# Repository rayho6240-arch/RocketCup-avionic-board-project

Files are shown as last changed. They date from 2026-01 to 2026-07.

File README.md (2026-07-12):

# 🚀 RocketCup Avionic Board Project (成大 ISP 航電組)

歡迎來到成大 ISP 航電組的協作平台！這裡存放了我們為比賽設計的所有電路圖、PCB 檔案以及相關硬體參考資料。

為了方便大家協作、快速找到規格書，我們對專案資料夾進行了全面整合與邏輯分類。請大家開發前務必詳細閱讀以下指南。

---

## 📂 檔案結構說明 (去哪裡找你的檔案與資料？)

我們採用結構化、模組化的資料夾配置。請在您負責的子專案資料夾內開發，並參考對應的規格書：

### 1️⃣ 核心開發專案 (由 Git 進行版本控制)
* **[hardware/big_avionic/](hardware/big_avionic/)**: 大火箭航電主板專區 (內附 `備注.md` 進度檔)。
* **[hardware/deployment_board/](hardware/deployment_board/)**: 降落與開傘部署板專區 (內附 `備注.md` 進度檔)。
* **[hardware/ground_station/](hardware/ground_station/)**: 地面接收站專區 (內附 `備注.md` 進度檔)。
* **[hardware/small_avionic/](hardware/small_avionic/)**: 小火箭航電備份板專區 (包含 Joyce、Ray、Tank、Tony 的開發分支，內附 `備注.md` 進度檔)。
* **[hardware/libraries/](hardware/libraries/)**: 共用的核心 KiCad 零件庫 (Symbol & Footprint)。

> 📌 **開發小筆記**：每個開發資料夾下都有一個 **`備注.md`**。請在裡面記錄您的設計要點、遇到的 Bug，並隨著開發勾選進度 Checkbox，讓其他組員知道目前的開發狀況！

### 2️⃣ 整理後的硬體參考資料 (建議在本地參考，不頻繁變動)
* **[Datasheets/](Datasheets/)**: 收納了 13 個重命名後的 PDF 規格書與硬體指南，標註了晶片型號與硬體用途（如：`ADXL375_High_G_Accelerometer_Datasheet.pdf`），一目了然！
* **[hardware/libraries/](hardware/libraries/)**: 收納了參考用的 KiCad 零件庫壓縮檔與解壓資料夾（如 `ul_*` 庫）。
* **[documentation/](documentation/)**: 存放 PDR 簡報、競賽評分表以及系統繪圖檔。
* **[hardware/ground_station/](hardware/ground_station/)**: 存放地面站電路圖。

---

## 文件導覽 (韌體 / 教學 / 歷史)

韌體、教學與專案歷史文件已整理歸檔如下：

* **[教學/教學_6_24.md](教學/教學_6_24.md)**：最新完整版開發教學（三角色架構、板間鏈路與不對稱備援、雙鏈路遙測協定、地面站、主機端測試）。
* **[PROJECT_HISTORY.md](PROJECT_HISTORY.md)**：專案演進史，記錄重大決策與轉折的「為什麼」。
* **[docs/](docs/README.md)**：工程／規劃文件索引（硬體規格表、改進計劃、進度、設計筆記、需求驗證、測試方法）。

> **韌體建置請以頂層 [`Makefile`](Makefile) 為準**：`make`（主航電）、`make build-backup`（備援）、`make build-ground`（地面站）、`make host-test`（純邏輯測試）。
> 工具鏈**必須使用 STM32CubeIDE 內建的 arm-none-eabi gcc**（Makefile 會優先讀取 `local.mk` 自訂路徑，無設定則自動偵測 macOS 預設路徑），**請勿使用 Homebrew 版**。
> 注意：航電專案目錄已更名為 `firmware/main_flight_code`；本文件下方早期撰寫的「VS Code / Homebrew」段落僅供歷史參考，現行建置一律以頂層 `Makefile` 與 `教學/教學_6_24.md` 第 11 節為準。

---

## ⚡ 每日開發流程 (SOP)

為了避免「悲劇」（檔案衝突或覆蓋），每次開工前請牢記口訣：**「先拉，再做，後推」**。

### 1️⃣ 開工第一件事：拉取 (Pull)
**只要你剛坐下準備開始畫圖，請先在 `RocketCom` 資料夾下執行：**
```bash
git pull origin main
```
* **為什麼？** 這能把雲端最新的進度同步到你的電腦。如果不拉就改，上傳時會發生嚴重冲突。

### 2️⃣ 進行開發
* 打開 KiCad，編輯您負責的原理圖或 PCB。
* 記得隨時存檔 (Ctrl+S)。
* **請更新您子專案目錄下的 `備注.md` 以更新開發進度！**

### 3️⃣ 收工上傳三部曲：加、存、推
當您完成一個階段的工作（例如：畫完電源線、擺完去耦電容），請依序執行：

**Step A: 加入變更 (Add)**
```bash
git add .
```

**Step B: 提交紀錄 (Commit)**
寫下您到底改了什麼。！！！絕對不要有啥都沒有描述的空 commit！！！
```bash
git commit -m "清楚的描述，例如：完成主航電板的 3.3V 電源佈線並更新備註"
```

**Step C: 推送到雲端 (Push)**
這一步才會把檔案真正上傳到 GitHub。
```bash
git push origin main
```

---

## 💣 KiCad 協作特別注意事項 (必讀！)

### 1. 關於 PCB 檔案 (`.kicad_pcb`)
Git 很擅長合併程式碼，但**非常不擅長合併二進位/圖形化的 PCB 檔**。
* ⚠️ **黃金法則**：同一時間，**只能有一個人**修改同一張 PCB 板。
* **開發前溝通**：要改 Layout 之前，請在群組喊一聲，確認目前沒人正在編輯再動手。

### 2. 優化後的 `.gitignore` 說明
我們已經全面升級了 `.gitignore`，能自動遞迴忽略以下不必要的檔案：
* KiCad 自動產生的原理圖與 PCB 備份檔 (`*.kicad_sch-bak`, `*.kicad_pcb-bak`)。
* 個人視窗配置檔 (`*.kicad_prl`，避免每個人螢幕大小不同導致衝突)。
* 作業系統垃圾檔（如 macOS 的 `.DS_Store` 與 Windows 的 `Thumbs.db`）。
* 開發快取檔（如 `fp-info-cache`）。
* *請勿強行上傳這些垃圾檔，以保持專案倉庫的輕量與整潔！*

---

## ❓ 常見問題救生圈

### Q1: 我輸入 `git push` 時出現 `error: failed to push some refs...` 怎麼辦？
代表有人在您工作的期間，已經先上傳了新版本。
**解法：**
1. 先輸入 `git pull origin main` (把對方的東西抓下來自動合併)。
2. 如果不幸出現衝突 (Conflict)，請找組長求救。
3. 合併成功後，再輸入一次 `git push origin main`。

### Q2: 為什麼有些備份檔 (`.bak`, `-bak`) 傳不上去？
這是正常的！我們在 `.gitignore` 中設定了過濾，這些是不需要的暫存備份檔。

## 🛠️ 輕量化 STM32 開發與編譯指南 (VS Code / Antigravity IDE)

日常編碼、編譯與燒錄**不需要每次打開重型的 STM32CubeIDE**：在 VS Code / Antigravity IDE 的終端機，直接呼叫**倉庫根目錄的頂層 [`Makefile`](Makefile)**，即可完成主控專案 [firmware/main_flight_code/](firmware/main_flight_code/) 的極速編譯與燒錄。

### 1️⃣ 工具鏈 (Toolchain)：支援使用者自訂本地路徑
本專案**必須使用 STM32CubeIDE 內建的 `arm-none-eabi` gcc 與 `STM32_Programmer_CLI`**，**請勿**用 `brew install` 安裝任何 ARM GCC（例如 `gcc-arm-none-eabi`）——版本不同會造成連結或燒錄問題。

* **本地路徑自訂**：預設使用 macOS 系統路徑。若您在非 macOS 系統（Windows/Linux）或安裝在其他路徑，**請複製 `local.mk.example` 並重新命名為 `local.mk`**，在裡面自訂您的 `CUBEIDE_PLUGINS` 路徑。
* `local.mk` 已經在 `.gitignore` 中設定忽略，不會被提交上傳，保障每位開發者可以使用本機專屬的編譯路徑。
* 頂層 `Makefile` 會自動從 `local.mk`（或預設路徑）載入工具鏈，編譯／燒錄時自動帶入 `PATH`。

> 📌 此為現行唯一正確的工具鏈規範，詳見 [`教學/教學_6_24.md`](教學/教學_6_24.md) 第 11 節與頂層 [`Makefile`](Makefile)。

### 2️⃣ 在 IDE 終端機進行極速編譯 (頂層 Makefile)
**請在倉庫根目錄 `RocketCom/` 下執行**（不要再 `cd` 進子資料夾）。一份程式碼可建置三種角色：

```bash
make               # 編譯主航電 (ROLE_PRIMARY，預設目標)
make build-backup  # 編譯備援航電 (ROLE_BACKUP)
make build-ground  # 編譯地面站   (ROLE_GROUND)
make host-test     # 純邏輯主機端測試（免上板）
make clean         # 清除建置產物
```

編譯成功後，產物在 `firmware/main_flight_code/Debug/` 下（皆已被 `.gitignore` 忽略，不佔倉庫）：
* **`Main_AV_F407.elf`** — 主航電的除錯／燒錄檔（即頂層 `Makefile` 的 `ELF` 變數）
* 連帶產生 `Main_AV_F407.bin`、`Main_AV_F407.list`、`Main_AV_F407.map`
* `Main_AV_F407_backup.elf` / `Main_AV_F407_ground.elf` — 備援／地面站變體（由 `build-backup` / `build-ground` 產生）

### 3️⃣ 一鍵燒錄與序列埠監看
```bash
make flash          # 編譯 + 以 ST-Link SWD 燒錄主航電 .elf
make flash-backup   # 編譯並燒錄備援航電
make flash-ground   # 編譯並燒錄地面站
make monitor        # 開序列埠監看（自動偵測序列埠 @460800；可用 PORT=/dev/cu.xxx 覆寫，Ctrl+A 後按 K 離開）
make all            # 等同 flash + monitor
```

若偏好在 IDE 內單步除錯，可安裝 **Cortex-Debug** 擴充套件，並在 `.vscode/launch.json` 中配置 ST-Link 除錯器，即可按 **F5** 一鍵燒錄與中斷點除錯。

*(註：若你未來在 `.ioc` 中新增或修改了硬體引腳，請打開 `firmware/main_flight_code/Main_AV_F407.ioc` 點擊儲存重新 Generate；其餘日常編碼、編譯與燒錄皆可在本 IDE 終端機以上述 `make` 指令快速完成。)*

---

## 🔧 環境設定檢查

* **KiCad 版本**：請大家統一使用 **KiCad 9.0.7**，避免原理圖或 PCB 檔案格式相容性出錯。
* **Git 個人化設定**：第一次使用請設定您的名字和 Email：
```bash
git config --global user.name "你的名字(英文)"
git config --global user.email "你的Email"
```
彩蛋： 唯一不是AIIIIIIII寫的

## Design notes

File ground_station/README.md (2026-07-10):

# Ground Station — 地面站主機軟體

> **本資料夾只負責存放地面站「主機端軟體」（在 PC 上執行的 Python 工具）。**
> 硬體與韌體不放這裡：
> - 地面站硬體（KiCad PCB / footprint）→ [`../hardware/ground_station/`](../hardware/ground_station/)
> - 地面站 CubeMX 韌體設定 → [`../firmware/ground_station_mx/`](../firmware/ground_station_mx/)

## 內容

| 項目 | 說明 |
| :--- | :--- |
| `serial_link.py` | 串口連線與收發核心 |
| `telemetry_decoder.py` | 遙測封包解碼 |
| `gui/` | 上位機 GUI：`ground_gui.py`、`gui_monitor.py`、`requirements.txt` |
| `tools/` | 分析工具：`ekf_visualizer.py`、`realtime_charts.py`、`test_runner.py` |
| `logs/` | 執行時串口紀錄輸出（runtime 產物） |

## 使用

```bash
pip install -r gui/requirements.txt
python serial_link.py        # 命令列串口工具
python gui/ground_gui.py     # 圖形介面
```

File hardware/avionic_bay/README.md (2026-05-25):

# 📐 Avionic Bay (航電艙機械與結構設計)

這裡存放我們火箭航電艙（Avionics Bay）的 3D CAD 設計模型、機構設計、實體裝配說明以及 3D 列印 STL 檔案。

---

## 📂 檔案結構建議 (Directory Structure)

您可以將機械設計相關檔案存放在此：
* `CAD/`：存放 Fusion 360 / SolidWorks 的原始 `.step` 或 `.f3d` 零件與裝配體模型。
* `STL/`：存放用於 3D 列印的 `.stl` 或是 `.gcode` 切片檔（例如防震疊板固定架、天線底座）。
* `Drawings/`：存放工程圖、開孔尺寸圖（特別是氣壓計排氣開孔尺寸）。

---

## 🔍 航電艙物理設計核心注意事項 (Avionics Bay Best Practices)

為確保感測器與射頻通訊能正常工作，請在設計航電艙實體結構時，務必遵循以下航太工程標準：

### 1. 氣壓計靜壓艙與排氣孔設計 (Static Port Venting)
* **目的**：`BMP390` 氣壓計必須測量火箭艙外的「靜態氣壓」才能換算精確高度。如果艙體全密封，高度計將完全失效；如果排氣孔設計不當，高速飛行時的「動壓」會導致高度計讀數嚴重偏低或誤判頂點！
* **設計黃金法則**：
  1. 在航電艙外側的圓柱面上，精確鑽設 **3 到 4 個均勻分布的靜壓孔 (Static Ports)**（直徑通常在 1.5mm 至 3.0mm 之間，具體取決於艙體容積）。
  2. 靜壓孔內部可黏貼細緻的「防風海綿 (Venting Foam)」，阻擋外部高速亂流與強光直射氣壓計。
  3. **機艙避光設計 (Light Shielding)**：氣壓計內部的矽半導體對光線敏感，強烈陽光直射會導致高度計讀數出現數十公尺的階躍誤差！請確保航電艙內部結構具備良好的避光性（可用黑色膠帶或遮光隔板）。

### 2. 射頻天線固定與接地 (RF Antenna Mounting)
* **通訊阻礙防範**：若火箭艙體使用碳纖維（Carbon Fiber）或金屬材質，這會形成電磁屏蔽（法拉第籠），阻擋無線電波！
  * **解法**：航電艙段的艙體外殼建議統一使用**玻纖（Fiberglass）**、**紙管**或 **3D 列印 (PLA/ABS/PETG)** 等非導電材質。
  * **天線擺放**：LoRa 天線應垂直架設，並盡量遠離大片金屬結構與高頻噪聲源（如 DCDC 晶片）。

### 3. 電池抗震與固定 (Battery Ruggedization)
* 火箭發射時將面臨劇烈的震動與高達數十個 G 的瞬時衝擊（Shock）。
* 🔋 **電池固定法則**：
  * **絕不能僅用雙面膠或魔鬼氈固定電池**！必須設計實體的**電池盒 (Battery Holder)**，配合束帶或機械鎖緊。
  * 電池接頭（如 JST, XT30）必須設有**防脫落卡扣或絕緣膠帶纏繞**，防止飛行中因震動斷電導致航電系統停擺！

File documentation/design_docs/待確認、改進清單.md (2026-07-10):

# 🚀 成大 ISP 航電主控系統 — 待確認與改進清單 (To-Confirm & Improvement Checklist)

此清單用於追蹤系統在實際上架、模擬發射與實彈測試前，必須進行硬體對齊、軟體數值推導或系統壓測的待確認事項。

---

## 📋 待確認清單 (To-Confirm)

- [ ] **1. 開傘機構與持續時間確認**
  - **副傘點火導通時間：** 目前在 `fsm.h` 中 `FSM_PYRO_HOLD_MS` 設定為 2000ms (2秒)。需配合實際點火頭與火藥量，測試 2 秒的導通時間是否能保證點燃，且不會因高溫熔毀短路引起板子死機。
  - **主傘釋放舵機角度：** 目前主傘釋放舵機在 `STATE_MAIN_DEPLOY` 下以 TIM4_CH3 PWM (CCR=2000) 控制轉動。需現場實測舵機的機械連桿與扣具角度，確保鎖定 (0°) 與釋放 (90°) 位置不會卡死。

- [ ] **2. 頂點絕對失效保護安全時間鎖推導**
  - **背景：** `FSM_FAILSAFE_APOGEE_MS` 目前暫定為 15000ms (15秒)。
  - **待辦：** 必須在發射前以 **OpenRocket** 進行該級火箭的彈道模擬，取 $1.5 \times t_{\text{apogee\_sim}}$ (模擬頂點時間) 重新填入。必須確保此值大於模擬頂點時間 5 秒以上，且小於主傘看門狗時間 5 秒以上。

- [ ] **3. 主傘安全看門狗時間確認**
  - **背景：** `FSM_MAIN_WATCHDOG_MS` 目前設定為 25000ms (25秒)。
  - **待辦：** 需結合發射場高度與降落速度模擬，確認 25 秒是否足夠讓火箭完全度過頂點下墜至安全開傘高度，避免在高速下墜中強開主傘導致傘繩扯斷。

- [ ] **4. ADXL375 高-G 加速度計軸向對齊實機驗證**
  - **背景：** 因 PCB 佈線軸向相反，`sensor_axis.h` 中對 ADXL375 的 X 與 Y 軸數據進行了取負值 (Inversion) 的修正。
  - **待辦：** 在地面搖晃或震動航電板，在 GUI Monitor 上對比 `BMI088` 與 `ADXL375` 的三軸輸出，確保在同一 Body Frame (X=右, Y=前, Z=上) 下，重力方向與震動方向方向完全一致。

- [ ] **5. SD 卡插拔檢測與無卡防空狀態驗證**
  - **背景：** `SDIO_DET` 引腳 (PD3) 已從 `GPIO_NOPULL` 改為內建 `GPIO_PULLUP` 以防止無卡時總線超時卡死主迴圈。
  - **待辦：** 測試在「拔除 SD 卡」的狀態下開機，確認系統能優雅跳過掛載日誌流程，且 LoRa 遙測與 EKF 任務能 100% 正常工作、無當機復位現象。

- [ ] **6. 地磁計 MMC5983MA 的 SET/RESET 橋偏校準頻率**
  - **背景：** 目前在非飛行狀態下每 10 秒執行一次 `MMC5983_Recalibrate()` 來補償溫飄。
  - **待辦：** 確認在發射架上等待發射時，地磁融合角度是否會因為校準產生跳變；飛行中地磁計已被隔離，但需確認這 10 秒一次的 recalibrate 不會影響起飛判定。

---

## 🛠️ 改進與優化清單 (Improvements)

- [ ] **1. Flash Ring Buffer 寫入頻率與 Sector 擦除分離 (極重要)**
  - **現狀：** 目前飛行階段寫入頻率限制在 50Hz 而非 100Hz，因為 `FlashRing_WritePacket` 內含 Sector 擦除（最壞需耗時 400ms 阻塞），若開到 100Hz 會卡住主任務的數據同步。
  - **目標：** 將 Flash 擦除邏輯移到獨立的低優先級 FreeRTOS 任務中，透過 `g_spi3_mutex` 互斥鎖與 `StartDefaultTask` 協調，將飛行寫入頻率安全提升至 100Hz。

- [ ] **2. 壓測 SPI3 總線並發性能 (SX1268 LoRa + W25Q128 Flash)**
  - **現狀：** Flash 寫入與 LoRa 遙測共同掛載在 SPI3 總線上。
  - **目標：** 進行壓力測試，模擬同時進行 50Hz 數據寫入與 5Hz 遙測傳輸，確認互斥鎖沒有造成優先級反轉 (Priority Inversion) 或導致高優先級飛控任務的延遲。

- [ ] **3. SPI3 共用匯流排單點故障隔離與超時保護 (避免單一故障拖垮總線)**
  - **現狀：** Flash 寫入（W25Q128）與 920MHz LoRa 模組（E80）共用 `SPI3` 匯流排。若單一設備損壞（如 MISO 接地短路或晶片內部故障），一旦 SPI 傳輸函數或忙碌等待（如 `W25QXX_WaitForReady`）在無防護的 `while` 迴圈中卡死，或因佔用 `g_spi3_mutex` 互斥鎖不放，將導致整個 SPI 總線癱瘓，波及其他共用設備並造成主控程序阻塞。
  - **目標：** 
    1. 在所有 SPI 傳輸與等待 Ready 的等待迴圈中加入嚴格的計數器超時機制，禁止無限 `while` 等待。
    2. 建立硬體健康評估機制。若開機 ID 讀取異常（如讀到全 `0x00` 或全 `0xFF`）或執行中 SPI 連續傳輸超時失敗達到設定閥值，應自動標記該設備為「失效（offline）」，並在後續程序中主動跳過對該設備的 SPI 存取與 `g_spi3_mutex` 鎖定，確保其他正常設備能繼續穩定運作。

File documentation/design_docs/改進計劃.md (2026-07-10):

# RocketCom 改進計畫(飛行安全優先)

> 產出日期:2026-06-11(`total_test` branch)。本文件為整體程式碼審計後制定的分級改進路線圖。
> 優先原則:**火箭尚未首飛**,P0 = 任何會導致「該開傘時不開傘 / 不該點火時點火 / 失機」的問題,飛行前必須全數完成;程式碼整潔度與工具鏈問題往後排。
> 驗證雙軌:每項安全變更必附 **host 單元測試**(`cd tests && make run`,比照 `test_sensor_axis.c` 模式)+ **HIL 上板驗證**(test_runner.py,PD13 接 LED、無火工品)。

---

## 一、風險總覽表(審計發現,已逐項對源碼驗證)

| 編號 | 嚴重度 | 風險 | 後果 | 證據(檔:行) |
|---|---|---|---|---|
| R1 | 🔴 CRITICAL | COAST 態無絕對時間備援:EKF 向上發散(v_est 恆>0、h_est 爬升)時頂點條件永不成立 | **副傘永不點火 → 彈道墜地失機**(25s 看門狗在 DESCENT 態,點火後才到得了) | main.c:1464-1501 |
| R2 | 🔴 CRITICAL | `FSM_Update()` 呼叫點位於 `if (bmi088_ok && batch_ready)` 條件塊內 | BMI088 初始化失敗或飛行中批次斷流 → **FSM 整個停止執行**,連失效保護都不會跑 | main.c:2130 |
| R3 | 🔴 CRITICAL | EKF 無任何防護:P 無上界、baro 創新值無閘控(±10km 跳變照收)、無 NaN 偵測、無狀態界限 | 單筆壞值/感測器故障 → 估計發散 → 誤開傘或不開傘 | ekf.c:370-431 |
| R4 | 🔴 CRITICAL | 無感測器失效偵測(rate_monitor 僅診斷顯示用) | 卡死/失流感測器持續餵 EKF 與 FSM,零察覺 | 全域 |
| R5 | 🟠 HIGH | 點火 GPIO 前有 ~9ms 阻塞 printf;起飛/燒完判定單靠 ADXL375 一顆 | 開傘動作被 UART 延遲;ADXL 死 → 起飛偵測剩 EKF 單路 | main.c:1492→1496, 1446 |
| R6 | 🟠 HIGH | 預擦池僅 10 sectors(50Hz 寫入 ≈10.2s 飛行量),之後每 ~1s 一次最壞 400ms 同步滾動擦除,阻塞 defaultTask 並持 SPI3 mutex | 擦除窗口內 FSM 不跑、EKF 斷饋、可能正落在頂點窗口 | w25qxx.h:204, w25qxx.c:512-517 |
| R7 | 🟠 HIGH | 熱啟動強設 `EKF_calibrated=1` 不驗證校準資料、不讀 ring 封包「副傘已點火」旗標 | 空中斷電重啟 → **二次點火**或用壞校準飛行 | main.c:1905-1921 |
| R8 | 🟡 MEDIUM | 1kHz 飛行迴圈內:ADC 輪詢 10ms 逾時、10Hz CSV printf 每次 ~8.7ms 阻塞 UART | 飛控迴圈抖動、EKF 樣本時序失真 | main.c:1564, 2275 |

**其他發現**(納入 P1–P3):雙份 Flash 驅動(w25q128.h/c 與 w25qxx.h/c)、CRC16 重複實作、E22 init 靜默吞 AUX 逾時、E80 RF 參數待上板驗證(硬體未到)、PD6 BUSY EXTI 設 IT_RISING_FALLING 造成 ISR 風暴、host 測試僅 test_sensor_axis.c 一支(EKF/FSM/telemetry/GPS/flash ring 全無機器驗證)、test_runner.py / gui_monitor.py / ekf_visualizer.py 三份重複 serial 邏輯、77-byte 遙測封包尚無地面站解碼器、repo 垃圾檔(`X`/`Y`/`Z`/`-X`/`-Y`/`-Z`/`實際`、~6.5MB log)與 .gitignore 缺項。

---

## 二、P0 飛行安全(依賴順序 A→B→C→D→E→F,每項一個 commit)

```
P0-A FSM 抽離(地基:純邏輯 host 可測)
  └→ P0-B 頂點失效保護 + baro 趨勢交叉檢查
       └→ P0-C EKF 防護(ekf_guard.h,健康位餵 FSM)
            └→ P0-D 感測器健康(餵 EKF 閘控 + FSM + 遙測)
                 └→ P0-E 飛行迴圈阻塞消除
                      └→ P0-F 熱啟動安全化
```

### P0-A:FSM 抽離為純邏輯模組(行為保存重構)

| 項目 | 內容 |
|---|---|
| 目標 | 安全邏輯改動前先讓 FSM 可被 host 測試逐 cycle 驗證;順手根治 R2 與 R5 的 printf 延遲 |
| 變更檔案 | 新增 `Core/Inc/fsm.h`、`Core/Src/fsm.c`、`tests/test_fsm.c`;修改 `main.c`、`main.h`、`tests/Makefile` |
| 設計 | `FSM_Step(FSM_Context_t*, const FSM_Input_t*) → FSM_Action_t`。輸入快照:now_ms / h_est / v_est / ekf_healthy / a_z_g / baro_alt_rel / sensor_bits / ekf_calibrated。輸出動作:fire_drogue / release_drogue / deploy_main / start_buzzer / event。fsm.h 僅依賴 stdint,不含 HAL(比照 sensor_axis.h 模式)。`FSM_Context_t` 收納原 static 變數 + `drogue_fired` 鎖存;`FSM_Init()` 帶 `drogue_already_fired` 供熱啟動。`FlightState_t` enum 自 main.h 移入 fsm.h |
| main.c 變更 | 原 FSM_Update(1425-1562)改為薄包裝:組輸入 → `FSM_Step` → **先執行動作(GPIO/PWM/buzzer)再 printf**;`ctx->state` 鏡射回全域 `current_fsm_state`(telemetry/flash/SD 讀取零漣漪)。呼叫點自 BMI088 條件塊移出,改主迴圈無條件 100Hz 定時呼叫 |
| 行為保存 | 第一步逐字搬移、不改任何閾值;test_fsm.c 黃金飛行剖面鎖定現行為後才進 P0-B |
| Host 測試 | 標稱剖面(PAD→…→LANDED 各轉移時刻 ±1 cycle、各動作恰一次)、PAD 雜訊不誤觸、tick 溢位場景、FSM_Init 各態進入 |
| HIL | `make build` 過、開機進 PAD、PD13 恆 LOW、[RATE] 正常、無 IWDG 重啟;桌面浸泡無誤轉移(請使用者執行 30 分鐘版) |
| DoD | host 全綠 + build 乾淨 + 上述 HIL 斷言通過 |

### P0-B:頂點失效保護 + baro 原始趨勢交叉檢查(修 R1)

| 項目 | 內容 |
|---|---|
| 變更檔案 | `fsm.c/h`、`main.h`(參數)、`telemetry.c/h`(flag)、`tests/test_fsm.c` |
| 絕對計時器 | `FSM_FAILSAFE_APOGEE_MS 15000U`:起飛起算,**BOOST 與 COAST 都生效**(burnout 判定失效卡 BOOST 也救),超時強制轉 APOGEE 點火,遙測標 `TELEM_FLAG_FAILSAFE 0x40` |
| baro 交叉檢查 | COAST 中追蹤 baro 原始相對高度滾動峰值,`峰值 − 當前 ≥ 10.0m` 連續 20 週期(200ms)即成立 apogee(第三 OR 條件,完全不依賴 EKF;同時是 EKF unhealthy 時的主開傘路徑) |
| 起飛冗餘 | 起飛判定加第三條件 `baro_alt_rel > 20.0m`;pad_ref 於 PAD 期每 30s 緩慢重零(抗氣象漂移),起飛後凍結 |
| 參數理由 | 15s:由 150m 主傘目標 + 25s 全程看門狗反推,此級別火箭頂點 ~8–12s,15s 高於合理頂點 ≥3s 且比主傘看門狗早 10s。10m:≈BMP388 噪聲(σ≈0.6m)的 16σ,不致誤觸;頂點後自由落體 10m 僅 ~1.4s |
| Host 測試 | EKF 卡升+baro 正常 → 交叉檢查於真頂點 ±1.5s 點火;EKF+baro 全死 → 計時器 15.00s 點火恰一次;baro 死 → 原 EKF 路徑不變;卡 BOOST → 計時器仍點火 |
| ⚠️ 飛行前義務 | **`FSM_FAILSAFE_APOGEE_MS` 為無模擬資料下的保守暫定值,飛行前必以 OpenRocket 重推 `1.5 × t_apogee_sim`(且 ≥ t_apogee_sim+5s、≤ 主傘看門狗 −5s)** |

### P0-C:EKF 防護最小集(修 R3)

| 防護 | 參數 | 理由 |
|---|---|---|
| baro 創新值閘控 | 拒收 `\|y\| > max(5·sqrt(S), 25.0m)` | 5σ 標準卡方閘;25m 絕對下限防收斂後(5σ≈3m)誤拒真實氣壓暫態 |
| 持續拒收偵測 | 連續 ≥200 次(@200Hz≈1s)→ `EKF_HB_BARO_DIVERGE` | 區分單發雜訊與估計已發散;不吞壞值,由 FSM 降級接手 |
| P 對角夾限 | 位置 ≤1e4 m²、速度 ≤2.5e3 m²/s²、下限 1e-6 | 防 baro 中斷時 P 無界增長、恢復瞬間增益爆炸 |
| 狀態理智界限 | pos_z∈[−100,+2000]m、vel_z∈[−200,+350]m/s、水平 \|pos\|≤5000m、\|vel\|≤200m/s | 由本箭剖面(150m 主傘、25s、數百米頂點)放大一個數量級 |
| NaN 掃描 | 每 buffer 一次;NaN → P 重設、vel 清零、pos_z 拍至最近接受的 baro、q 正規化或 identity;`EKF_HB_NAN` 黏滯 5s | NaN 即全毀,必須重建 |
| baro 逾時 | >500ms 無被接受的 baro → `EKF_HB_BARO_TIMEOUT`;FSM 端另查 EKF 最後更新距今 >300ms 視同 unhealthy | 涵蓋 EKF_Task 餓死/queue 斷流 |

- 變更檔案:新增 `Core/Inc/ekf_guard.h`(純 header-only)、`tests/test_ekf_guard.c`;修改 `ekf.c/h`(掛載點:UpdateBaroDelayed 入口、predict 收尾、buffer 迴圈尾)、`telemetry.c/h`(`TELEM_FLAG_EKF_UNHEALTHY 0x10`)
- API:`EKF_GetHealthBits()` / `EKF_IsHealthy()`(critical-section 快照,同 EKF_GetState 模式)
- **FSM 降級策略**(EKF unhealthy 時,fsm.c 內 raw-baro 鏈):頂點 = P0-B 趨勢規則;主傘 = `h_fb ≤ 200m` 或 25s 看門狗;落地 = 2s 內 |Δh_fb|<2m 且 h_fb<30m
- HIL:浸泡期健康位恆 0(誤報率,**誤報降級本身也是風險**);`FAULT_INJECT_BARO_JUMP` 旗標驗拒收

### P0-D:感測器健康最小集(修 R4)

- 新增 `Core/Inc/sensor_health.h`(純邏輯)+ `tests/test_sensor_health.c`;main.c 批次提取點掛 Feed
- 偵測:**失流**(批次間隔 >100ms,正常 10ms)、**卡死**(raw 連續同值 ≥1s;ADC 噪聲使正常感測器幾乎不可能)、**範圍**(baro 26–110kPa、temp −40~85°C、|highg|≤250g,越界持續 0.5s)
- **消費端(本項重點,偵測而不消費沒有意義)**:
  1. baro fault → EKF 樣本 `has_baro=0` → 觸發 `EKF_HB_BARO_TIMEOUT` → FSM 降級鏈
  2. FSM 輸入快照帶 `sensor_bits`(起飛冗餘、fallback 閘控)
  3. telemetry `TELEM_FLAG_SENSOR_FAULT 0x20` + 1Hz `[HEALTH]` 診斷行
- 失效鏈(每環有 host 測試):IMU 卡死 → EKF 漂移 → baro 創新值持續拒收 → DIVERGE → FSM 降級 raw-baro → 仍可開傘

### P0-E:飛行迴圈阻塞消除(修 R6、R8)

1. **飛行中擦除禁令**:FSM 態 ∈ BOOST..MAIN_DEPLOY 不做滾動擦除;下一 sector 未預擦 → 丟該筆 + `g_ring_drop_count++`(遙測可觀測)
2. **PAD 期背景預擦**:目標 64 sectors(64×51÷50Hz ≈ 65s 飛行量,>2× 全程);開機仍擦 10 個維持開機時間,其餘 PAD/INIT 態每 1s 擦 1 個(單次最壞 400ms < IWDG 2.05s)。**發射檢核表:上架後等待 `[FLASH] pool=64` 再起飛** |
3. **ADC**:`ADC_Read_Battery_mv` 逾時 10ms→2ms;呼叫頻率降至 1Hz(`g_bat_voltage_mv` 本就是快取)
4. **printf 閘控**:BOOST..MAIN_DEPLOY 抑制 10Hz CSV 遙測行(每次 ~8.7ms;SD/Flash/LoRa 記錄不受影響);FSM 事件單行保留(已在動作之後)
5. **可觀測性**:每秒印 `[LOOP] max_ms` 單迴圈最大耗時水位;HIL 斷言飛行態 <20ms、`g_ekf_queue_drops` 不再遞增

### P0-F:熱啟動安全化(修 R7)

- main.c 熱啟動塊(1905-1921)重寫為 `HotStart_TryRestore()`,**驗證鏈全過才恢復,任一失敗回 STATE_PAD 完整重校準**:
  1. `FlashRing_GetLastPacket` CRC 有效
  2. SysFlags 校準區 magic+CRC 有效才設 `EKF_calibrated=1`
  3. 合理性:`pkt.tick_ms < 60000`(飛行不可能超 60s)、封包 baro 與當下首筆 baro 差 <300m
  4. **重點火政策:`pkt.flags & 0x01`(drogue 已點火)→ 恢復至 STATE_DESCENT,杜絕二次點火**;未點火且原態 COAST → 恢復 COAST 可正常點火
- 成功置 `TELEM_FLAG_HOTSTART 0x80`;熱啟動路徑跳過開機預擦迴圈(省 ~2s)
- Host 測試:四象限(已/未點火 × 各態)+ 驗證鏈各單項失敗回 PAD;HIL:bench 飛行中斷電重啟,斷言恢復態正確、PD13 不重複導通(請使用者執行)

---

## 三、P1 穩健性與測試安全網

1. EKF 垂直通道重置:`BARO_DIVERGE` 持續 >3s → pos_z 拍至 baro、vel_z 取 baro 斜率、P z 列重設
2. 進度.md item G 完整版:獨立低優先 Flash 擦除任務(SPI3 mutex 已備),移除 P0-E 的丟包妥協
3. item B:ADXL TIM3 ISR 讀取移任務 + SPI1 mutex(設計文件 `設計_ADXL375_EKF融合與SPI1並發.md` 已備);BMI088 長期死亡時 ADXL375 全程替饋 EKF
4. Host 測試補洞:`test_telemetry.c`(打包/CRC 黃金向量,CRC-16/CCITT-FALSE "123456789"→0x29B1)、GPS NMEA 解析抽純函式 + 截斷旗標修復、flash ring 迴繞數學抽 header 測試
5. LoRa 健壯化:E22 AUX 逾時 → `lora433_ok=0` + 任務層重試;**PD6 BUSY EXTI 改純 input**(杜絕 E80 SPI 期間 ISR 風暴);E80 RF 參數驗證(🔴 **blocked:待硬體**)
6. test_runner.py 擴充:`[HEALTH]`/`[LOOP]` 水位斷言、`HIL_FSM_BENCH` 自動化序列
7. 遙測封包正式加 `health_bits`/`sensor_bits` 兩 byte(與 P3 地面站解碼器同步改,契約一次到位)
8. 各任務堆疊水位印出(`uxTaskGetStackHighWaterMark` 0.2Hz);printf 改 UART2 DMA 環形緩衝(解 defaultTask/EKF_Task 並發 HAL_UART_Transmit 競態)
9. **SPI 共用總線單點故障隔離與超時保護**：在 W25Qxx 與 LoRa E80 的 SPI 讀寫/忙碌等待中引入計數器軟體超時保護；若 ID 校驗失敗或連續超時，自動將設備標記為離線（degraded）並跳過該設備後續的 SPI 讀寫與 `g_spi3_mutex` 鎖定，避免單點硬體故障（如 MISO 接地）拖垮整個 SPI3 總線與共用任務。

## 四、P2 可維護性

1. 合併 `w25q128.c` → `w25qxx.c`(保留 Flash_DumpAll);`ring_crc16`/`telem_crc16` 統一 `crc16.h` 單實作
2. main.c(2490 行)分解:感測器批次管線 → `sensors_pipeline.c`、SD 記錄 → `datalog.c`(保留 CubeMX USER CODE 區塊結構)
3. 開 `-Wall -Wextra` 清零警告;殘餘魔術數字集中(P0 已收大半)
4. 文件刷新:進度.md 路線圖狀態(item A 其實已在 commit 7218650 完成)、code_structure.md 與實作同步(如飛行迴圈實際 1kHz/FSM 100Hz vs 文件 100Hz)

## 五、P3 工具與衛生

1. **地面站解碼器**(最重要的 P3):`GroundStation/telemetry_decoder.py` 依 telemetry.h 契約解 77-byte 封包(sync 0xA5,0x5A 對齊 + CRC + seq 丟包統計);抽 `serial_link.py` 收斂 test_runner / gui_monitor / ekf_visualizer 三份重複 serial 邏輯,port/baud 進設定檔
2. Repo 清理:刪 junk 檔(`X` `Y` `Z` `-X` `-Y` `-Z` `實際`)與 ~6.5MB `*.log`;.gitignore 加 `*.log`、`*_autosave*`、`bom/`
3. `requirements.txt`(pyserial/numpy/matplotlib 釘版本);根 Makefile 加 `host-test` target
4. Debug/subdir.mk 手動加檔的脆弱性寫入 README(CubeIDE regen 會自動納入,屬已知行為,修復非急務)

---

## 六、飛行前必驗 Checklist(P0 全部完成後)

- [ ] `cd tests && make run` 全綠(test_sensor_axis + test_fsm + test_ekf_guard + test_sensor_health)
- [ ] `make build` 乾淨通過(CubeIDE gcc 13.3)
- [ ] test_runner.py HIL:[RATE] 達標、[HEALTH] 健康位恆 0、[LOOP] 飛行態 <20ms、PD13 恆 LOW
- [ ] 30 分鐘 PAD 浸泡:零誤轉移、零誤點火、無 IWDG 重啟、健康位零誤報
- [ ] `HIL_FSM_BENCH` 縮放閾值:手動觸發起飛 → 全狀態瀑布 + 失效計時器點火時刻碼表實測
- [ ] 故障注入(`FAULT_INJECT_*`):baro 卡死/跳變 → 健康位、遙測 flag、降級鏈逐環確認
- [ ] bench 斷電重啟:熱啟動恢復正確、**絕不二次點火**
- [ ] **以 OpenRocket 模擬重推 `FSM_FAILSAFE_APOGEE_MS`**(1.5×t_apogee,暫定 15s 必須被取代)
- [ ] 上架後等待 `[FLASH] pool=64` 訊息再允許點火起飛
- [ ] E80 920MHz RF 參數對照規格書逐項驗證 + 地面站收包(待硬體)

## 七、新增參數速查表

| 參數 | 值 | 位置 | 飛行前需重推導? |
|---|-----|---|---|
| `FSM_FAILSAFE_APOGEE_MS` | 15000U | main.h | **是(OpenRocket 1.5×t_apogee)** |
| `FSM_BARO_APOGEE_DROP_M` | 10.0f | main.h | 否(16σ 噪聲餘裕) |
| `FSM_BARO_APOGEE_CONSEC` | 20(200ms) | main.h | 否 |
| 起飛 baro 冗餘門檻 | 20.0m | main.h | 否 |
| baro 創新閘 | max(5σ, 25m) | ekf_guard.h | 否 |
| P 對角上限 | pos 1e4 / vel 2.5e3 | ekf_guard.h | 否 |
| 狀態界限 | z∈[−100,2000]m, vz∈[−200,350]m/s | ekf_guard.h | 視箭型(目前剖面足夠) |
| 感測器失流/卡死/範圍 | 100ms / 1s / 0.5s | sensor_health.h | 否 |
| 預擦池目標 | 64 sectors | w25qxx.h | 飛行 >60s 需加大 |
| 遙測 flags 新位 | 0x10 EKF_UNHEALTHY / 0x20 SENSOR_FAULT / 0x40 FAILSAFE / 0x80 HOTSTART | telemetry.h | — (地面站解碼器同步) |

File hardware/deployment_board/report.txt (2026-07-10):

資訊: 正在處理符號 'C1:Capacitor_SMD:C_0805_2012Metric_Pad1.18x1.45mm_HandSolder'。
資訊: 正在處理符號 'J4:'。
資訊: 正在處理符號 'D6:'。
資訊: 正在處理符號 'D5:'。
資訊: 正在處理符號 'C2:Capacitor_THT:C_Radial_D18.0mm_H35.5mm_P7.50mm'。
資訊: 正在處理符號 'D2:Diode_SMD:D_0805_2012Metric_Pad1.15x1.40mm_HandSolder'。
資訊: 正在處理符號 'D3:'。
資訊: 正在處理符號 'D1:Diode_SMD:D_0805_2012Metric_Pad1.15x1.40mm_HandSolder'。
資訊: 正在處理符號 'F1:'。
資訊: 正在處理符號 'D4:'。
資訊: 正在處理符號 'GND1:'。
資訊: 正在處理符號 'J1:'。
資訊: 正在處理符號 'J2:'。
資訊: 正在處理符號 'J3:'。
資訊: 正在處理符號 'J5:'。
資訊: 正在處理符號 'M1:'。
資訊: 正在處理符號 'Q1:'。
資訊: 正在處理符號 'Q2:'。
資訊: 正在處理符號 'Q3:Package_TO_SOT_SMD:SOT-23'。
資訊: 正在處理符號 'R1:'。
資訊: 正在處理符號 'R2:'。
資訊: 總計警告: 0, 錯誤: 22。
資訊: 正在處理符號 'R3:Resistor_SMD:R_0805_2012Metric_Pad1.20x1.40mm_HandSolder'。
資訊: 正在處理符號 'R4:'。
資訊: 正在處理符號 'R5:'。
資訊: 正在處理符號 'R6:'。
資訊: 正在處理符號 'R7:'。
資訊: 正在處理符號 'SW1:'。
資訊: 正在處理符號 'V_D_BAT+1:'。
已將 C2 封裝篩選器更新為 'C_*'。
將 C2 接腳 1 連接到了 V_Ｄ_BAT+。
將 C2 接腳 2 連接到了 GND。
添加了 D1 (封裝 'Diode_SMD:D_0805_2012Metric_Pad1.15x1.40mm_HandSolder')。
已將 REF** 的參考位置更改為 D1。
已將 D1 的值從 'D_0805_2012Metric_Pad1.15x1.40mm_HandSolder' 修改為 'D_Schottky'。
將 D1 符號分配從  更新到 /afddf6cc-838e-4f23-90be-1837a1aae5c3。
已更新 D1 個欄位。
已將 D1 圖紙名稱更新為 '/'。
已將 D1 圖紙檔案更新為 'Deployment board.kicad_sch'。
已將 D1 封裝篩選器更新為 'TO-???* *_Diode_* *SingleDiode* D_*'。
添加網路 Net-(D1-K)。
將 D1 接腳 1 連接到了 Net-(D1-K)。
添加網路 Main_AV_PWM_Servo。
將 D1 接腳 2 連接到了 Main_AV_PWM_Servo。
添加了 D2 (封裝 'Diode_SMD:D_0805_2012Metric_Pad1.15x1.40mm_HandSolder')。
已將 REF** 的參考位置更改為 D2。
已將 D2 的值從 'D_0805_2012Metric_Pad1.15x1.40mm_HandSolder' 修改為 'D_Schottky'。
已更新 D2 個欄位。
已將 D2 圖紙名稱更新為 '/'。
已將 D2 圖紙檔案更新為 'Deployment board.kicad_sch'。
已將 D2 封裝篩選器更新為 'TO-???* *_Diode_* *SingleDiode* D_*'。
將 D2 接腳 1 連接到了 Net-(D1-K)。
添加網路 Backup_AV_PWM_Servo。
將 D2 接腳 2 連接到了 Backup_AV_PWM_Servo。
將 D2 符號分配從  更新到 /3689029c-2b9c-4e80-b576-72a362e14549。
添加了 C1 (封裝 'Capacitor_SMD:C_0805_2012Metric_Pad1.18x1.45mm_HandSolder')。
已將 REF** 的參考位置更改為 C1。
已將 C1 的值從 'C_0805_2012Metric_Pad1.18x1.45mm_HandSolder' 修改為 '100n'。
將 C1 符號分配從  更新到 /8f363f78-229f-41fa-81e6-f160d2b571a7。
已更新 C1 個欄位。
已將 C1 圖紙名稱更新為 '/'。
已將 C1 圖紙檔案更新為 'Deployment board.kicad_sch'。
已將 C1 封裝篩選器更新為 'C_*'。
添加網路 GND。
將 C1 接腳 2 連接到了 GND。
添加網路 V_Ｄ_BAT+。
將 C1 接腳 1 連接到了 V_Ｄ_BAT+。
添加了 C2 (封裝 'Capacitor_THT:C_Radial_D18.0mm_H35.5mm_P7.50mm')。
添加了 R3 (封裝 'Resistor_SMD:R_0805_2012Metric_Pad1.20x1.40mm_HandSolder')。
已將 REF** 的參考位置更改為 R3。
已將 R3 的值從 'R_0805_2012Metric_Pad1.20x1.40mm_HandSolder' 修改為 '1k'。
將 R3 符號分配從  更新到 /a728b347-bfb4-432d-a141-ddc5c2a8a8d3。
已更新 R3 個欄位。
已將 R3 圖紙名稱更新為 '/'。
已將 R3 圖紙檔案更新為 'Deployment board.kicad_sch'。
已將 R3 封裝篩選器更新為 'R_*'。
將 R3 接腳 1 連接到了 Net-(D1-K)。
將 R3 接腳 2 連接到了 GND。
已將 REF** 的參考位置更改為 C2。
已將 C2 的值從 'C_Radial_D18.0mm_H35.5mm_P7.50mm' 修改為 '1000u'。
將 C2 符號分配從  更新到 /1a8924d4-40a4-46ed-bfbd-bdd772b5f900。
已更新 C2 個欄位。
已將 C2 圖紙名稱更新為 '/'。
已將 C2 圖紙檔案更新為 'Deployment board.kicad_sch'。

錯誤: 無法添加 GND1 (沒有分配封裝)。
錯誤: 無法添加 M1 (沒有分配封裝)。
錯誤: 無法添加 D6 (沒有分配封裝)。
錯誤: 無法添加 Q1 (沒有分配封裝)。
錯誤: 無法添加 J1 (沒有分配封裝)。
錯誤: 無法添加 Q2 (沒有分配封裝)。
錯誤: 無法添加 D3 (沒有分配封裝)。
錯誤: 無法添加 J2 (沒有分配封裝)。
錯誤: 無法添加 R2 (沒有分配封裝)。
錯誤: 無法添加 R1 (沒有分配封裝)。
錯誤: 無法添加 R5 (沒有分配封裝)。
錯誤: 無法添加 F1 (沒有分配封裝)。
錯誤: 無法添加 R6 (沒有分配封裝)。
錯誤: 無法添加 J3 (沒有分配封裝)。
錯誤: 無法添加 R7 (沒有分配封裝)。
錯誤: 無法添加 D5 (沒有分配封裝)。
錯誤: 無法添加 SW1 (沒有分配封裝)。
錯誤: 無法添加 J4 (沒有分配封裝)。
錯誤: 無法添加 V_D_BAT+1 (沒有分配封裝)。
錯誤: 無法添加 D4 (沒有分配封裝)。
錯誤: 無法添加 J5 (沒有分配封裝)。
錯誤: 無法添加 R4 (沒有分配封裝)。

資訊: 總計警告: 0, 錯誤: 22。

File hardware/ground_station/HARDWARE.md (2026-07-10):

# 🛠️ ESP32 + E22-T30D Ground Station Hardware Setup Guide

This document provides a detailed bill of materials (BOM), schematics, wiring pinouts, power calculation, and assembly instructions for building the portable, independent 18650 battery-powered ground station.

---

## 1. Bill of Materials (BOM)

| Component | Description | Est. Cost (TWD) | Note |
| :--- | :--- | :--- | :--- |
| **ESP32 NodeMCU-32S** | Standard 38-pin DevKit (ESP-WROOM-32 chip inside) | ~$100 | Dual-core, built-in USB-TTL (CP2102) |
| **E22-400T30D** | Ebyte SX1268 433MHz 30dBm (1W) UART LoRa Module | ~$250 | Or **E22-900T30D** (915MHz) depending on rocket |
| **433MHz SMA Antenna** | High-gain rubber ducky antenna or spring antenna | ~$50 - $150 | Must match module frequency |
| **18650 Battery Shield V3** | Integrated charge/discharge protection & 5V boost | ~$80 | Typically uses TP4056 + IP5306 or equivalent |
| **18650 Li-ion Battery** | Nominal 3.7V, capacity > 2500mAh (e.g., Samsung/LG) | ~$120 | Reclaim from old laptops or buy new |
| **Jumper Wires & Switch** | Female-to-Female dupont wires, slide switch | ~$30 | For breadboard or soldering |

---

## 2. Power Supply Design & Safety

### ⚠️ Critical Warning
> [!CAUTION]
> **NO DIRECT BATTERY TO ESP32 3.3V:**
> A fully charged 18650 battery outputs **4.2V**. The ESP32 chip's absolute maximum rating is **3.6V**. Connecting the 18650 directly to the 3.3V pin will burn out the ESP32.
>
> **NO DIRECT BATTERY TO ESP32 5V (VIN):**
> If you connect the battery (3.0V - 4.2V) to the ESP32 board's `5V/VIN` pin, it passes through an onboard LDO regulator (e.g. AMS1117-3.3) which has a **1.1V - 1.3V dropout voltage**. When the battery drops to its nominal **3.7V**, the output of the LDO becomes `3.7V - 1.1V = 2.6V`. This voltage is too low, causing the ESP32 to brown out, crash, or fail to start.

### The Solution: 18650 Battery Shield V3
By using an off-the-shelf **18650 Battery Shield V3**, we solve both issues:
1. **Charging Circuit:** Features a TP4056 lithium battery charger chip to safely charge the 18650 cell via Micro-USB/Type-C.
2. **Protection Circuit:** Features a DW01 (overcharge/over-discharge protection) to prevent battery swelling and degradation.
3. **5V Boost Converter:** Utilizes a highly efficient DC-DC boost converter (e.g. IP5306 or similar) to step up the battery voltage to a stable **5.0V** (capable of outputting up to 2.0A).
4. **Stable Power Distribution:**
   - The boosted stable **5V** is fed directly into the **E22 VCC** (ensures full 30dBm / 1W transmit power).
   - The boosted stable **5V** is fed into the **ESP32 5V/VIN** pin (the onboard 3.3V LDO now receives a steady 5V and outputs a clean 3.3V for the ESP32 chip).

---

## 3. Power Consumption & Battery Life Estimation

*   **ESP32 Power Consumption:**
    *   CPU Active (Receive only, no Wi-Fi/BT): **~60mA**
    *   Wi-Fi/Bluetooth enabled (optional): **~160mA - 240mA**
*   **E22-T30D Power Consumption:**
    *   Receive Mode (Listening): **~16mA**
    *   Transmit Mode (30dBm / 1W peak): **~650mA**

### Operational Lifespan Calculation
Assuming the ground station is primarily in **Receive Mode** (only listening to the rocket telemetry) and Wi-Fi is disabled:
$$\text{Total System Current} = 60\text{ mA (ESP32)} + 16\text{ mA (E22)} \approx 76\text{ mA}$$

Accounting for a $85\%$ boost converter efficiency:
$$\text{Average Draw from 3.7V Battery} = \frac{76\text{ mA} \times 5.0\text{V}}{3.7\text{V} \times 0.85} \approx 120\text{ mA}$$

For a standard **3000mAh** 18650 battery:
$$\text{Battery Life} = \frac{3000\text{ mAh}}{120\text{ mA}} \approx 25\text{ Hours}$$
The ground station can run continuously for **over 24 hours** on a single charge!

---

## 4. Hardware Wiring & Pin Mapping

Ensure all power is disconnected before wiring. Connect the pins as shown in the table below:

| E22-T30D Pin | Wire Color (Rec.) | ESP32 GPIO | Description | Note |
| :--- | :--- | :--- | :--- | :--- |
| **VCC** | Red | **5V / VIN** | 5V Power Input | Connect to 5V output solder pad of the Battery Shield |
| **GND** | Black | **GND** | Common Ground | Connect to GND solder pad of the Battery Shield |
| **TXD** | Yellow | **GPIO 16 (RX2)**| UART Data Out | Outputs received data from E22 to ESP32 RX2 |
| **RXD** | White | **GPIO 17 (TX2)**| UART Data In | Receives commands/telemetry from ESP32 TX2 |
| **AUX** | Blue | **GPIO 15** | State Indication | High = Idle, Low = Processing/Busy |
| **RST** | Purple | **GPIO 13** | Module Reset | Pull low to reset E22 hardware |
| **M0** | Orange | **GPIO 21** | Mode Control 0 | Controls working mode of E22 |
| **M1** | Brown | **GPIO 22** | Mode Control 1 | Controls working mode of E22 |

> [!IMPORTANT]
> **Common Ground:** Ensure the ESP32 Ground, E22 Ground, and the 18650 battery shield Ground are all tied together to establish a common reference voltage.

---

## 5. Wiring Schematic (Breadboard View)

```
       +---------------------------------------------+
       |           18650 Battery Shield              |
       |  [Bat Charger] ----> [5V Boost Converter]   |
       |                        |            |       |
       +------------------------|------------|-------+
                                | 5V         | GND
                                |            |
         +----------------------+            +--------+
         |                      |                     |
         v 5V/VIN               v VCC                 v GND
  +--------------+       +--------------+      +--------------+
  |              |       |              |      |              |
  |    ESP32     |       |   E22 T30D   |      | Common GND   |
  |  NodeMCU-32S |       |  LoRa Module |      |   Bus Bar    |
  |              |       |              |      |              |
  |    GPIO16    |<------|     TXD      |      |              |
  |    GPIO17    |------>|     RXD      |      |              |
  |    GPIO15    |<------|     AUX      |      |              |
  |    GPIO13    |------>|     RST      |      |              |
  |    GPIO21    |------>|     M0       |      |              |
  |    GPIO22    |------>|     M1       |      |              |
  |              |       |              |      |              |
  |     GND      |       |     GND      |      |              |
  +-------+------+       +-------+------+      +-------+------+
          |                      |                     |
          +----------------------o---------------------+
```

---

## 6. Step-by-Step Assembly Instructions

### Step 1: Install Antenna
*   **WARNING:** Always screw the SMA antenna onto the E22 module **BEFORE** applying power. Operating a transmitter without an antenna can instantly destroy the RF power amplifier due to impedance mismatch (high VSWR).

### Step 2: Assemble Power Source
*   Insert the 18650 battery cell into the slot on the battery shield. Verify the polarity matches the markings (`+` and `-`).
*   Charge the battery fully using a USB charger connected to the shield's charging port until the status LED changes to green/blue.

### Step 3: Connect Control and Logic Pins
*   Using female-to-female jumper wires (or soldering onto a perfboard), connect the E22 control pins (`M0`, `M1`, `AUX`, `RST`, `RXD`, `TXD`) to the designated ESP32 GPIOs as specified in Section 4.

### Step 4: Hook Up Power Rails
*   Connect the E22 `VCC` pin and the ESP32 `5V / VIN` pin to the `5V` output terminals/solder pads on the battery shield.
*   Connect both `GND` pins to the `GND` terminal/solder pad on the battery shield.

### Step 5: Double Check
*   Ensure there are no short circuits between `5V` and `GND`.
*   Ensure `TXD` goes to `GPIO16 (RX)` and `RXD` goes to `GPIO17 (TX)` (crossing the lines is required).

### Step 6: Power Up!
*   Slide the battery shield power switch to the `ON` position.
*   The ESP32 onboard LED will flash to indicate it has started up.

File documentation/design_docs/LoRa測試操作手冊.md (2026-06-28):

# 📡 LoRa 通訊測試操作手冊（地面站 / ROLE_GROUND）

本手冊說明如何用一台電腦，透過地面站板的 **UART2** 即時調整 LoRa RF 參數
（E22 433MHz / E80 920MHz）並觀察通訊品質統計，用於 bring-up 與鏈路調校。

> 對應程式：
> - [`gs_lora_test.c`](../Main_Code/Core/Src/gs_lora_test.c) — UART2 命令介面 + 雙鏈路統計
> - [`lora_calc.h`](../Main_Code/Core/Inc/lora_calc.h) — 純換算 / 統計（host 可測，見 [`tests/test_lora_calc.c`](../tests/test_lora_calc.c)）
> - [`lora_e80.c`](../Main_Code/Core/Src/lora_e80.c) — **LR1121** 驅動（E80）
> - [`lora_e22.c`](../Main_Code/Core/Src/lora_e22.c) — E22 透傳驅動

---

## 1. 架構概觀

```
                 ┌─────────────────── 地面站板 (ROLE_GROUND) ───────────────────┐
   ┌────────┐    │  UART2 (PA2/PA3, 460800 8N1)                                 │
   │   PC   │◄──►│   ├─ RX：解析文字命令（調頻率/SF/BW…、查統計）              │
   │ 終端機 │    │   └─ TX：printf 回應、統計輸出（測試「控制台」）            │
   └────────┘    │                                                              │
                 │  E22 433MHz (UART3 透傳)  ─┐                                  │
                 │  E80 920MHz (LR1121, SPI3)─┴► telem_rx 解析 → 統計           │
   ┌────────┐    │                                                              │
   │USB-CDC │◄───┤  USB 虛擬序列埠：串流收到的遙測 CSV（資料「資料流」）       │
   │ (資料) │    │                                                              │
   └────────┘    └──────────────────────────────────────────────────────────────┘
                            ▲ 下行遙測        ▼ 上行手動開傘命令（433 反向，見 §7）
                 ┌──────────┴────────────────┴──┐
                 │        火箭主航電             │  下行：E22 433 + E80 920
                 │  E22 每 10 槽空 1 槽聽上行    │  上行：地面 433 → 火箭手動開傘
                 └──────────────────────────────┘
```

**兩條序列埠各司其職：**
| 埠 | 用途 | 鮑率 |
| :-- | :-- | :-- |
| **UART2** (PA2/PA3) | 測試控制台：打命令、看統計與回應 | 460800 8N1 |
| **USB-CDC** | 純資料流：收到的遙測 CSV（給記錄/繪圖） | USB 虛擬埠 |

---

## 2. 硬體接線

E22 / E80 已焊在航電板上（接線見 [連線和基本硬體規格表.md](連線和基本硬體規格表.md)）。
測試只需把 **UART2** 接到電腦：

| 地面站板 | USB-TTL 轉接器 (如 CP2102/CH340) |
| :-- | :-- |
| `PA2` (USART2_TX) | RXD |
| `PA3` (USART2_RX) | TXD |
| `GND` | GND |

> ⚠️ TX↔RX 必須交叉。USB-TTL 的 VCC **不要**接（板子自有供電）。
> ⚠️ 轉接器邏輯準位須為 **3.3V**（勿用 5V TTL 直連 STM32）。

天線：E22 / E80 **務必接好對應頻段天線**再上電，空載發射可能損壞 PA。

---

## 3. 編譯與燒錄

```bash
make build-ground      # 編譯地面站 binary（BOARD_ROLE=ROLE_GROUND）
make flash-ground      # 編譯 + 透過 ST-Link 燒錄
```

> 主/備航電不受影響：`gs_lora_test` 整檔以 `#if IS_GROUND` 包住。

---

## 4. 連線終端機

序列埠參數：**460800 / 8 / N / 1**，無流量控制。

macOS（內建 screen）：
```bash
ls /dev/cu.usbserial-*          # 找出轉接器埠號
screen /dev/cu.usbserial-XXXX 460800
# 離開：Ctrl-A 再按 K，然後 y
```
或用 `minicom -D /dev/cu.usbserial-XXXX -b 460800`、CoolTerm、PuTTY 等。

> 命令以 **Enter** 結尾即可（程式接受 `\r`、`\n`、`\r\n`）。
> 上電後會看到：`[TEST] LoRa 通訊測試模組就緒（UART2 460800），輸入 help`

---

## 5. 命令參考

| 命令 | 說明 |
| :-- | :-- |
| `help` | 顯示命令清單 |
| `ver` | 顯示 E80(LR1121) 版本與初始化診斷（HW / Type=0x03 / Stat1） |
| `stats` | 顯示雙鏈路統計 |
| `stats reset` | 清除統計計數器 |
| `stats auto <sec>` | 每 N 秒自動列印統計（`stats auto 0` 關閉） |
| `e22 freq <mhz>` | 設 E22 頻率 410–493 MHz（寫入 EEPROM，掉電保留） |
| `e22 show` | 顯示 E22 目前頻率 / 通道 |
| `e80 freq <hz>` | 設 E80 中心頻率（Hz，例 `e80 freq 915000000`） |
| `e80 sf <7-12>` | 設 E80 展頻因子 |
| `e80 bw <idx>` | 設 E80 頻寬 index（見 §8） |
| `e80 cr <1-4>` | 設 E80 編碼率（1=4/5 … 4=4/8） |
| `e80 pwr <dbm>` | 設 E80 發射功率 −9~22 dBm |
| `e80 pre <n>` | 設 E80 前導碼長度 6~65535 |
| `e80 show` | 顯示 E80 RF 參數 + 空中時間估算 |
| `e80 airtime <len>` | 估算指定 payload 長度的空中時間 / 等效 bitrate |
| `e80 init` | 重新初始化 E80（LR1121）並進入接收 |
| `e80 rxstart` | 重新進入連續接收 |

**統計輸出範例：**
```
[STATS] --- E80-920 ---
[STATS] pkt_ok=412  crc_err=3
[STATS] rate=9.8 pkt/s  elapsed=42s
[STATS] RSSI: last=-87 min=-95 max=-71 avg=-86 dBm
[STATS] SNR:  last=36 min=8 max=44 avg=30 (x0.25dB)   ← dB = 數值 ÷ 4
```
> E22 為透傳模式，**無逐包 RSSI/SNR**，只統計封包數 / CRC 錯誤 / 封包率。

---

## 6. 典型測試流程

### A. 快速健檢（確認 E80 在線）
```
ver           → Type 應為 0x03（LR1121）、Stat1 非 0x00/0xFF
e80 show      → 確認頻率/SF/BW 與火箭 TX 一致
stats auto 5  → 每 5 秒看統計，確認 pkt_ok 持續增加
```

### B. 比較不同 SF 的距離 / 穩定度
```
stats reset
e80 sf 7      → 走遠，記錄 rate / RSSI / crc_err
stats reset
e80 sf 10     → 同一距離再測，比較靈敏度與封包率
```
> SF 越高靈敏度越好但空中時間越長（`e80 show` 可看 airtime）。

### C. 掃頻找乾淨頻道
```
e80 freq 920000000
stats reset
stats auto 3
... 觀察 → 換 e80 freq 921000000 ... 比較 crc_err / RSSI 底噪
```

> ⚠️ **關鍵：地面站改參數只改「接收端」。** 要實際通訊，火箭主航電 TX 必須用
> **相同**的頻率 / SF / BW / CR / sync word。本工具用途是「找到好參數」，
> 找到後把同一組值同步寫到主航電（`lora_e80.c` / `lora_e22.c` 的 `#define`）兩邊一致。

---

## 7. 上行手動開傘（433 反向鏈路）

除了接收下行，地面站可經 **433 反向**打命令給火箭，**手動觸發開傘**（範圍安全 /
備援用途）。對應 [`uplink_proto.h`](../Main_Code/Core/Inc/uplink_proto.h)（框架，
火箭/地面共用）、[`uplink_cmd.c`](../Main_Code/Core/Src/uplink_cmd.c)（火箭端 RX +
武裝/點火）、`gs_lora_test.c`（地面送命令）。

### 7.1 運作原理（時間分割）

433 是單頻、半雙工：火箭在發下行時，地面送的上行會撞包。因此**火箭每 10 個下行
時槽空出 1 槽不發 433**（≈每 2 秒有 200ms 安靜窗，由 `UPLINK_LISTEN_EVERY` 控制），
此時 E22 透傳即在接收。地面命令以 **~3 秒 burst 重複送**（`UPLINK_TX_REPEAT`），
確保至少一筆落在安靜窗。920 下行不受影響、維持全速率。

```
火箭 433: [TX][TX][TX][TX][TX][TX][TX][TX][TX][靜聽] [TX][TX]...
                                              ▲ 地面 burst 命中此窗
```

### 7.2 安全：兩段式 ARM → DEPLOY

- **DEPLOY 命令只有在火箭「已武裝」時才會點火。** 先送 `arm`，再送 `deploy`。
- 武裝後 **30 秒**（`UPLINK_ARM_TIMEOUT_MS`）未開傘自動解除，避免遺留武裝。
- 命令框架有獨立 sync（`0x55 0xAA`）+ CRC-16，雜訊/誤碼不會誤觸（host 測試覆蓋）。
- 手動副傘 MOSFET 導通限時 `FSM_PYRO_HOLD_MS`(2s) 後自動斷開；主傘舵機維持釋放角度。
- 與既有 FSM 自動開傘**並存**：手動點火會鎖存 `drogue_fired`，FSM 不重複點火。
- 整功能由 `FEATURE_UPLINK_DEPLOY`（預設僅主航電）開關。

> ⚠️ 手動開傘一旦武裝後即可在**任何飛行狀態**生效（真正的人工覆寫）。地面操作者
> 須自行判斷時機（例如副傘誤在上升段開傘可能造成結構破壞）。ARM 步驟即為防誤觸閘。

### 7.3 操作步驟（地面站 UART2）

```
ping            → 確認上行通：火箭主控台應印出 [UPLINK] PING…（約 3s 內）
arm             → 火箭印 [UPLINK] *** ARMED ***
deploy drogue   → 火箭印 [UPLINK] *** 手動開傘 *** drogue=1
                  ↳ 確認：下行遙測 flags 出現 DROGUE_FIRED（PD13 實際導通推導）
disarm          → 不開傘時解除武裝
```

> **確認回路**：火箭點火後，下行 `DROGUE_FIRED` / `MAIN_DEPLOYED` 旗標（由 PD13 GPIO /
> TIM4 舵機實際狀態推導，非軟體自報）會翻為 1，地面站立即可見 —— 即「真的點了」的證據。

### 7.4 上板測試（不裝火藥）

1. 火箭端把 PD13 接 LED / 萬用表（或示波器），主傘看 TIM4_CH3 舵機。
2. 地面 `ping` 確認上行通 → `arm` → `deploy drogue`。
3. 觀察：火箭 LED 亮 2 秒後熄（限時保護）、下行 `DROGUE_FIRED` 旗標翻起再依硬體狀態。
4. 測 `arm` 逾時：`arm` 後等 >30s 再 `deploy`，應被拒（火箭印「未武裝」）。
5. 測未武裝保護：重開機後直接 `deploy`，應被拒。

---

## 8. ⚠️ 上板驗證清單（LR1121 板級項目）

E80-900M2213S 核心是 **Semtech LR1121**。下列為「板級」設定，集中在
[`lora_e80.c`](../Main_Code/Core/Src/lora_e80.c) 頂部 `#define`，**務必對照 E80
規格書逐項驗證**，否則最常見的症狀是「`ver` 正常但完全收不到封包」：

- [ ] **RF 開關真值表（最關鍵）** `E80_RFSW_*`
  LR1121 的 **DIO5=RFSW0、DIO6=RFSW1** 控制模組內建 RF 開關。預設採 Semtech
  LR1121 參考設計（RX=RFSW0 高、TX_HP=RFSW1 高）。若 E80 接線不同，**收發 RF 完全不通**。
  驗證：`ver` 能讀到 LR1121 但 `stats` 永遠 0 封包 → 高度懷疑此項。
- [ ] **參考振盪器** `E80_USE_TCXO`
  E80 內建 32MHz 主動式振盪器。預設 `0`（視為自供電 clipped-sine 進 XTA）。
  若 bring-up 顯示頻率嚴重偏移 / 收不到 → 試 `=1`（LR1121 供電 TCXO，須重校準）。
- [ ] **IRQ 對應的 LR1121 DIO**
  程式把 RX/TX 事件放在 `SetDioIrqParams` 的 **dio1 遮罩**，假設模組 INT 腳
  （板上 PD4/EXTI4）接 LR1121 **DIO9**。若實際接其他 DIO，需改 `e80_set_dio_irq()`。
  驗證：能收（`e80 init` 後手動 poll 有資料）但 `RxReady()` 一直 0 → 懷疑 IRQ 沒進。
- [ ] **頻率 / SF / BW / CR / sync word 與主航電一致**
  兩端任一不符即收不到。sync word 預設 `0x12`（私有）。
- [ ] **天線與功率** 發射端 22dBm，務必接天線；近距離測試可降 `e80 pwr` 避免飽和。

> 完成驗證後，請把確認過的數值更新到本手冊與 `lora_e80.c`，並於
> [進度.md](進度.md) / [待確認、改進清單.md](待確認、改進清單.md) 記錄。

---

## 9. 參數對照表

**LoRa 頻寬 index（`e80 bw <idx>`，LR1121 值）：**

| idx | 頻寬 | idx | 頻寬 |
| :-: | :-- | :-: | :-- |
| 0x03 | 62.5 kHz | 0x05 | 250 kHz |
| 0x04 | 125 kHz | 0x06 | 500 kHz |

（更窄：0x00=7.8k, 0x01=15.6k, 0x02=31.25k, 0x08=10.4k, 0x09=20.8k, 0x0A=41.7k）

**展頻因子：** SF7~SF12（值即數字）。**編碼率：** 1=4/5, 2=4/6, 3=4/7, 4=4/8。

**LDRO（低資料率最佳化）：** 由韌體自動依「符號時間 ≥ 16ms」判定
（例 BW125 下 SF11/SF12 自動開），無需手動設定。

**空中時間參考**（顯式表頭 + CRC on，preamble=8，payload≈79B 遙測封包，用 `e80 airtime` 即時算）：
SF 每 +1、空中時間約 ×2；BW ×2、空中時間約 ÷2。

---

## 10. 疑難排解

| 症狀 | 排查 |
| :-- | :-- |
| 終端機沒任何輸出 | 鮑率非 460800？TX/RX 沒交叉？GND 沒共地？ |
| 命令沒反應 | 有按 Enter？輸入 `help` 測試；確認轉接器 3.3V |
| `ver` Type≠0x03 / Stat1=0x00 或 0xFF | SPI 不通：MISO 接地(0x00)/浮空(0xFF)；查 CS/SCK/接線 |
| `ver` 正常但 `stats` 一直 0 封包（E80） | **RF 開關 `E80_RFSW_*`**（§8 第一項）；天線；與 TX 參數不一致 |
| E80 收不到、E22 正常 | LR1121 板級項（RF 開關 / IRQ DIO / TCXO） |
| E22 收不到、E80 正常 | E22 頻道與 TX 不符（`e22 show`）；UART3 接線；M0/M1 模式 |
| crc_err 很高 | 訊號弱（看 RSSI/SNR）、頻道干擾（換頻）、兩端參數不完全一致 |
| 改了參數後反而全斷 | 只改了地面站；火箭 TX 未同步成相同參數 |
| `deploy` 火箭沒反應 | 先 `arm`？ARM 是否已逾時(30s)？`ping` 先確認上行通 |
| `ping`/`arm` 火箭收不到 | 上行需命中安靜窗：命令是 ~3s burst，勿中途打斷；E22 兩端同頻同 NETID |
| `deploy` 印「未武裝」 | 正常保護：須先 `arm` 且在 30s 窗內 |

---

## 11. 附錄：為什麼 E80 驅動要對 LR1121 重寫

E80-900M2213S 的核心是 **LR1121**，與 SX126x 命令協定截然不同。早期驅動誤用
SX126x 指令集，在 LR1121 上**完全不會動作**。主要差異：

| 項目 | SX126x（錯誤假設） | LR1121（E80 實際） |
| :-- | :-- | :-- |
| opcode | 1 byte（`0x86`） | **2 bytes**（`0x020B`） |
| 設頻率 | `Frf=f·2²⁵/32e6` 公式 | **直接 Hz**，4 bytes 大端 |
| 讀回應 | 同一次 SPI 交易 | **獨立第二次交易**（先 Stat1） |
| LoRa 封包型態 | `0x01` | **`0x02`** |
| LoRa sync word | 2-byte 暫存器 `0x0740` | **1-byte** 命令 `0x022B` |
| IRQ 遮罩 | 16-bit | **32-bit**；狀態含於 GetStatus |
| PA / RF 開關 | SX126x PA | **HP PA + DIO5/DIO6 RF 開關（必設）** |

opcode 與位元組佈局依 Semtech LR1121 User Manual / SWDR001 驅動核對。
板級項（RF 開關真值表、TCXO、IRQ DIO）仍須依 §7 於實機驗證。

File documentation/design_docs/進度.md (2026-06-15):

# RocketCup Avionic Board - 專案開發進度與待辦事項

這裡記錄了成大 ISP 航電組的硬體送印狀態、硬體複用策略以及當前的開發里程碑。

---

## 目前 Git 分支節點

| 分支 | 最新 Commit | 日期 | 說明 |
|---|---|---|---|
| `main`（**當前**） | `65efacf` | 2026-06-12 | total_test 全量 merge（P0×6 + P1）+ Ray CAD merge + P1 後續（GPS/flash ring 加固、堆疊水位） |
| `total_test` | `469f36b` | 2026-06-11 | 已 merge 入 main（`82cd371`）：全系統整合 + LoRa 雙鏈路遙測 + P0 飛行安全改進 |
| `EKF_test` | `0a03cf8` | 2026-06-02 | 磁力計驅動 + GPS/磁力計融入 EKF + EKF 狀態原子讀取 / ADXL 死碼清理 / Flash 寫入速率分級 |
| `rayBranch` | `e634f13` | 已 merge | GPS / 磁力計 bring-up 實驗 |

**2026-06-15 變更（main）**：
- **停用 E80 920MHz + SPI3 單設備故障隔離** — `67c2b37`：E80 920 bring-up 有問題先關閉。`lora_e80.h` 加編譯期開關 `LORA920_ENABLE`（預設 0）。核心隔離：E80 與 W25Q128 Flash 共用 SPI3 SCK/MISO/MOSI，mutex 只防軟體競用、擋不住故障設備在 CS=HIGH 時仍驅動 MISO；故新增 `LoRaE80_Shutdown()`（CS 拉高 + RST 拉低保持，SX126x NRST=低→全腳高阻，自匯流排物理斷開），停用或偵測失敗一律走此路徑保護 Flash 飛行記錄。`LoRaE80_Init` 加早期 MISO 健康檢查（GetStatus=0x00 接地/0xFF 浮空即早退）。make build 0 警告，--gc-sections 回收未呼叫的 E80 init 碼 text −884B。**硬體修好後改回 `LORA920_ENABLE 1` 即恢復**。

**本 session 變更（main，2026-06-12，merge 後 P1 續作）**：
- **P1-GPS 解析加固** — `9f4d79f`：解析邏輯抽純 `gps_parse.h`（host 可測）；**修復截斷污染 bug**（超長句溢位後剩餘位元組被當新句、'$' 前雜訊與 UBX 二進位 ACK 也被組句 → 新版未見 '$' 不收、溢位 discard 至下一 '$'、truncated 可觀測）；`tests/test_gps.c` 65 案例（黃金句 checksum/經緯度 Python 預算、截斷回歸、端到端位元組流）
- **P1-Flash ring 迴繞數學** — `52b4866`：位址數學抽純 `flash_ring_math.h`；**修整環假池量資料損毀 bug**（erased_end 停 END+1 的舊語意在寫入指標迴繞後算出 15.9MB 假池 → 整圈寫入落未擦區靜默損毀；長 bench 浸泡數次即觸發）→ 正規化 erased_end ∈ [BASE,END]；`tests/test_flash_ring.c` 34 案例（含 byte 粒度假 flash 兩整圈 417,792 筆模擬，舊語意第二圈即崩紅）
- **P1-堆疊水位** — `035bca9`：0.2Hz `[STACK] main=/ekf=/lora=` 行（osThreadGetStackSpace 歷史最低剩餘）；test_runner.py 斷言各任務 ≥256 bytes
- **P3-工具收尾** — `65efacf`：根 Makefile `make host-test`、`requirements.txt`（pyserial/numpy/matplotlib）、.gitignore 補新測試二進位
- **P2-清警告** — `3b875f5`：ekf.c 兩處 `-Waddress-of-packed-member`（取 packed 成員位址傳給 MMC5983_SetOffsets）改經對齊區域陣列中轉；全量 clean 重編 0 警告
- **P2-雙 Flash 驅動合一** — `41f7dbf`：`w25q128.c/h`（373+119 行重複驅動）併入 `w25qxx.c`；`Flash_DumpAll` 改用 `W25QXX_*` API + offsetof 欄位解析（取代手寫偏移）；dump 過時數字修正（52→80 bytes/封包、50Hz 飛行率）；ELF text 因去重 −888 bytes
- **P3-串口邏輯收斂** — `35572d2`：新增 `serial_link.py`（DEFAULT_BAUD/PREFERRED_PORT 單一真相、auto_port 統一偵測優先序、open_serial 統一錯誤診斷）；test_runner/gui_monitor/ekf_visualizer 三腳本改用；GroundStation/telemetry_decoder.py 刻意保持自包含
- host 測試擴至 **266 案例全綠**（27+55+26+15+44+65+34）；`make build` 0 警告（ELF text=159404）
- **P2 唯一未做**：main.c 分解（~2500 行）—— 刻意延後至 bench 驗證後再動，上板前保持映像穩定優先於整潔

**前 session 變更（total_test，2026-06-11，依 `改進計劃.md` P0 飛行安全優先）**：
- 整體程式碼審計 + 分級改進計畫 `改進計劃.md`（風險總覽 R1–R8 / P0–P3 路線圖 / 飛行前 checklist）
- 整合工作快照 commit（先前 session 之 LoRa 雙鏈路遙測 + telemetry + soft_i2c + tests/ + Makefile，未提交部分補提交）— `538f0ef`
- **P0-A**：FSM 抽離為純邏輯模組 `fsm.c/h`（host 可測，`tests/test_fsm.c` 27 案例黃金剖面鎖定行為）；FSM 呼叫點自 BMI088 條件塊移出改 100Hz 定時（修 R2：BMI088 斷流 FSM 停擺）；硬體動作先於 printf（修 R5：點火前 ~9ms UART 阻塞）— `6e7e08b`
- **P0-B**（修 R1 副傘永不點火單點故障）：①頂點絕對失效保護 `FSM_FAILSAFE_APOGEE_MS=15s`（BOOST/COAST 皆生效，⚠️ 飛行前必以 OpenRocket 重推 1.5×t_apogee）；②baro 原始趨勢交叉檢查（峰值回落 10m × 200ms，完全不依賴 EKF，EKF 發散時在真頂點附近開傘）；③起飛第三冗餘 baro_rel>20m（pad_ref 於 PAD 期每 30s 重零）；遙測旗標 `TELEM_FLAG_FAILSAFE 0x40`；test_fsm 擴至 35 案例（EKF 卡升/全死/卡 BOOST/baro 失效閘控）— `b902d70`
- **P1-其他**：EKF `DIVERGE>3s` 垂直通道自救重置（高度拍 baro、vz σ=10m/s 重建，不再永久降級）— `45eb3be`；test_runner.py 新斷言（[HEALTH] 寬限 5s 後恆 0、[LOOP]≤450ms、[FLASH] pool 增長）— `944a054`；repo 衛生（junk 檔/8.8MB log 清除、.gitignore 補 `*.log`/`*_autosave*`/`bom/`/測試二進位）— `ee918cc`
- **P1-LoRa 健壯化**：PD6 LORA920_BUSY 自 EXTI IT_RISING_FALLING 覆寫為純輸入（USER CODE 區，杜絕 E80 SPI 期間 ISR 風暴）；E22 AUX 逾時不再靜默 → `LoRaE22_Init` 回傳 HAL_TIMEOUT、`lora433_ok=0`、遙測任務每 10s 重試
- **P1-遙測契約**：`crc16.h` 單一實作（取代 w25qxx/telemetry 兩份重複）；封包擴至 **79 bytes**（crc 前加 `health_bits`/`sensor_bits`，故障定位不再只靠 flags 摘要位）；新增 `tests/test_telemetry.c`（44 案例：CRC 黃金向量 0x29B1、全欄位 offsetof 鎖定 —— 改佈局必紅，強迫同步解碼器）；**新增地面站解碼器 `GroundStation/telemetry_decoder.py`**（sync 掃描+CRC+seq 丟包統計，`--port`/`--file`/`--selftest`，selftest 通過）
- **P0-F**（修 R7 熱啟動二次點火）：熱啟動改 `FSM_HotStartDecide()` 純函式驗證鏈（host 已測）—— 封包 CRC、狀態 ∈ BOOST..DESCENT、tick<60s（防上次飛行殘留資料誤恢復）、|封包 baro − 當下 baro|<300m；**封包 flags bit0（副傘已點火）→ 強制恢復 DESCENT + drogue_fired 鎖存，杜絕二次點火**；移除裸跳 `EKF_calibrated=1`（EKF_Init 已自 SysFlags CRC+magic 還原校準，損毀則走 P0-C 降級鏈）；恢復時以 `EKF_HotRestartRestore` 注入封包 EKF 高度/速度/四元數；遙測 `TELEM_FLAG_HOTSTART 0x80`；test_fsm 擴至 55 案例
- **P0-E**（修 R6/R8 飛行迴圈阻塞）：①飛行態（BOOST..MAIN_DEPLOY）**禁止 Flash 同步滾動擦除**（原最壞 ~400ms 阻塞主迴圈且持 SPI3 mutex），池耗盡丟該筆 + `FlashRing_GetDropCount()` 可觀測；②PAD 期背景預擦至 **64 sectors**（≈65s 飛行量，每 1s 擦 1 個，`[FLASH] pool=N/64` 1Hz 回報，⚠️ 發射檢核表：上架後等 pool 達標）；③ADC 電池讀取逾時 10→2ms 且自 50Hz Flash 寫入路徑移至 1Hz；④飛行態抑制 10Hz CSV printf（每行 ~8.7ms UART 阻塞）；⑤`[LOOP] max_us=` 1Hz 單迴圈耗時水位（HIL 斷言飛行態 <20ms 依據）
- **P0-D**（修 R4 感測器失效零偵測）：新增 `sensor_health.h`（純函式：失流>100ms/卡死 raw 同值≥1s/範圍越界 0.5s，初始化失敗自動視同失流）；main.c 三餵入點（BMI088/ADXL375/BMP388 批次提取處）+ 100Hz 彙整 `g_sensor_fault_bits`；**消費端**：BMP388 fault → EKF 樣本 `has_baro=0`（接通 P0-C 降級鏈）、FSM `FSM_SB_BARO_FAULT`、遙測 `TELEM_FLAG_SENSOR_FAULT 0x20`、1Hz `[HEALTH] sens=/ekf=` 診斷行；新增 test_sensor_health（15 案例）
- **P0-C**（修 R3 EKF 零防護）：新增 `ekf_guard.h`（純函式）+ ekf.c 三掛載點 —— baro 創新值閘控 `max(5σ,25m)`（±10km 壞值不再直接餵入）、連續拒收 1s → `EKF_HB_BARO_DIVERGE`、P 對角夾限（pos 1e4/vel 2.5e3）、狀態理智界限（z∈[−100,2000]m、vz∈[−200,350]m/s）、NaN/Inf 掃描即重建（P 回初值/高度拍至最後接受 baro/q identity）、baro 接受逾時 500ms；`EKF_GetHealthBits()`+`EKF_GetLastUpdateTick()`（FSM 端 >300ms 視同餓死）；**FSM 降級鏈**：unhealthy 時停用 EKF 三頂點路徑（防發散值誤點火），起飛=a_z/baro（不需校準）、主傘=baro≤200m、落地=2s 視窗 baro 穩定；遙測 `TELEM_FLAG_EKF_UNHEALTHY 0x10`；新增 test_ekf_guard（26 案例）+ test_fsm [7] 降級鏈（45 案例）

**前 session 變更（EKF_test）**：
- Buzzer 開機兩聲（TIM2 CH1）+ TIM2 32-bit ARR overflow 修正 — `98a3669`
- 修正 `main.c` line 262 注解（Flash 為 SPI3 非 SPI1）+ 進度/分支節點更新 — `a988775`
- 改善項目實作 #1：D（FPU context save 確認，無需改）/ I（EKF queue drop 計數）/ N（Flash dump 改 USER_BT1 觸發）— `88c5a3a`
- 改善項目實作 #2-E：SD 卡 FSM 驅動全程記錄（取代原 10 秒上限）— `5e7cd2f`
- 改善項目實作 #2-H：氣壓高度溫度補正（hypsometric + 開機鎖定發射台 T0）— `76c55b7`
- 改善項目實作 #3：A+B 設計文件 `設計_ADXL375_EKF融合與SPI1並發.md`（含 EKF 加速度單位不一致的前置阻斷項）— `6774799`
- 改善項目實作 #4-J：GPS 驅動實作（**USART6** NMEA-0183，循環 DMA + IDLE 接收，GGA/RMC 解析，融入 Flash ring buffer 經緯度與 1Hz [GPS] 遙測）。**修正計畫書的 UART 對應錯誤**：計畫原稿誤標 GPS=USART3，實際依硬體金標準（`連線和基本硬體規格表.md`）GPS(NEO-M9N)=**USART6**(PC6/PC7)、433MHz LoRa(E22)=USART3(PD9）— `8c195cb`
- 改善項目實作 #5-L：MMC5983MA 地磁計驅動（**I2C1** 0x30，18-bit one-shot 量測 + SET/RESET 橋式偏移自校；開機 ProductID 驗證、`[MAG]` 1Hz 遙測、發射台階段每 10s 自動重校）— `ace8625`
- 改善項目實作 #6：GPS 水平位置（E/N）融入 EKF（發射台第一筆有效定位鎖定原點，等距投影換算 ENU 位移 + Joseph-form 標量量測更新，R 隨衛星數縮放；**僅飛行中融合**，發射台因 ZUPT 歸零水平狀態而捨棄）— `ddbdd3c`
- 改善項目實作 #7：地磁計航向（yaw）融入 EKF（Mahony 傾斜補償，水平磁場參考投影至 ENU-East 僅約束航向；**僅發射台階段**校正陀螺 yaw 漂移，升空後純陀螺遞推）— `0ad175d`
  - ⚠️ 三項 EKF 相關融合（#6/#7）皆需 **HIL 實機驗證**：磁力計軸向與 IMU body frame 對齊（反向則於呼叫端取負號）、`Kp_mag`/GPS 量測噪聲 R 調參、GPS 原點鎖定時機。
- 改善項目實作 #8-O：`EKF_GetState()` 原子快照（`taskENTER_CRITICAL` 封拷貝，修正 EKF_Task 高優先搶佔 defaultTask 讀取造成的撕裂讀取）— `478329a`
- 改善項目實作 #9-M（部分）：`adxl375.c` 移除死碼/錯索引的重複 raw 解析（`z_raw` 誤用 `rx_data[4]`），釐清軸向約定；**不做** sign-flip（避免與 BMI088 raw 不一致）— `3266a0b`
- 改善項目實作 #10-F：Flash ring buffer 寫入速率依 FSM 分級（INIT/PAD 20Hz、飛行 50Hz、LANDED 1Hz）；飛行率取 50Hz 而非 100Hz，因滾動擦除阻塞，全速需先做 G — `0a03cf8`
- **本 session 暫緩（需上板 / HIL 或硬體）**：🔴 A（ADXL 融入 EKF，含 g↔m/s² 單位前置修正）、B（SPI1 ISR→task 重構 + mutex）皆已備設計文件 `設計_ADXL375_EKF融合與SPI1並發.md`；🟡 G（擦除移獨立任務，需 SPI3 mutex + 時序驗證）與其前置 C（SPI3 mutex 骨架）相依，建議與 G 同批做；🟢 K（LoRa E22 遙測）需實體模組與透傳協定驗證。
- **🚨 磁力計防鎖死架構最佳化：回歸軟體 I2C + 100Hz polling (2026-06-03)**：
  * **決策**：在評估 STM32F4 晶片硬體 I2C 嚴重的 silicon bug 鎖死（BUSY 旗標 stuck、DMA 未正常釋放等）後，考量到飛行震動與馬達噪聲干擾，決定完全停用「硬體 I2C + DMA」，改回**軟體 I2C (Bit-Bang) 100Hz 連續暫存器 polling 讀取**。該架構為純軟體 fixed-bound 迴圈，具有天然免疫 Errata 及不卡死 MCU 特性，安全保障火箭飛行控制。
  * **硬體走線與 GPS 鮑率修復**：實體板線路（PB7=SCL, PB8=SDA）與 GPS (USART6 38400 bps) 均能完美配合工作。

---

## 專案重大調整與複用策略

由於**成本預算考量**，我們對航電硬體進行了極大化的複用與簡化，目前調整如下：

### 1. 首批送印板子 (共 5 張)

首批打樣送印僅選擇以下 5 張核心電路板：

1. `newpower` (位於 `BigAvionic/power layer_new`) - 主航電電源層板
2. `lora` (位於 `BigAvionic/lora`) - 主航電無線遙測通訊層板
3. `mainmcu` (位於 `BigAvionic/Second_layer_MCU`) - 主航電核心主控層板
4. `top` (位於 `BigAvionic/top_layer`) - 主航電頂層接口板
5. `Deployment board` (位於 `Deployment board/`) - 開傘部署控制板

### 2. 複用與替代策略 (Cost Optimization)

- **副航電備份板 (SmallAvionic) -> 由 `mcu layer` 代替**
  - 取消原先獨立設計的 `SmallAvionic` 系列（如 Joyce、Ray、Tank、Tony 版）。
  - 直接採用主航電四層疊板中的 `mainmcu` (MCU Layer) 單板作為備份副航電板，實現硬體完全一致性與零額外打樣費。
- **地面接收站 (GroundStation) -> 由 `BigAvionic` 整體四層疊板代替**
  - 取消原本獨立的 `GroundStation` 地面站 PCB 打樣。
  - 由於 `BigAvionic` 整體四層疊板已配備完整的 STM32 主控、LoRa 射頻收發與 USB-TTL 界面，地面接收站將直接使用一套完整組裝的 `BigAvionic` 四層疊板代替。

### 3. 預算最佳化方案 - 二合一合併板

- `Production_MCU_TOP_2_in_1` (原名 Production_MCU_LORA_2_in_1)
  - 實際上為 `top layer` (頂層板) 與 `mcu` (主控板) 合成的二合一合併板。
  - 用於作為未來量產或高度整合時的低成本備選方案（減少一張板子的打樣費用）。

---

## 實地測試里程碑 (Testing Milestones)

- **2026-06-03：電子羅盤實體線路接反與 GPS 鮑率錯誤重大定位與軟體戰術救援成功**
  - **實測發現**：實體板上 I2C1_SCL 誤接至 PB7，I2C1_SDA 誤接至 PB8，使晶片硬體 I2C 功能（PB7 限 SDA, PB8 限 SCL）受限，發送與接收訊號完全錯置；且 GPS 預設工作在 38400 bps 與軟體原配置之 115200 bps 不匹配。
  - **解決方案**：
    1. **軟體 I2C 救急**：編寫專用軟體模擬 I2C (Bit-Bang) 驅動，定義 SCL=PB7, SDA=PB8，採用 Open-Drain 開漏輸出並搭配板上 2.7kΩ 實體上拉電阻，實現在「不修改電路板」的前提下完美起死回生 MMC5983MA，實測遙測讀取高達 `ok=921, err=0`！
    2. **鮑率修正**：將 `huart6` (USART6) 鮑率修正為 38400 bps，實現 GPS 語句 `ok=60, err=0` 零校驗錯誤高速對齊！
    3. **新增頻率觀測**：在 `rate_monitor` 擴充 MMC5983MA 與 GPS 實測 Hz 統計，將 `[RATE]` 行升級回報。
  - **硬體物理優化建議**：由於頂層接口板 (Top Board) 與主控板 (MCU Board) 是透過 **JST-GH 連接線** 連接。如果日後希望恢復標準的 STM32 硬體 I2C1，**完全不需要重新打樣 PCB！只需要用細針或鑷子挑開並對調該 JST-GH 連接線接頭中的 PB7 與 PB8 兩根線針位置**，即可在硬體層面物理修復交換，並切換回原本的硬體 I2C 代碼！

- **2026-06-01：Buzzer 開機提示音實作（兩聲漸高）**
  - 實測結果：透過 TIM2 CH1 PWM（timer clock = 1 MHz，輸出腳 PA0）實現開機兩聲提示音（2 kHz → 4 kHz，各 100 ms，間隔 100 ms），於 `StartDefaultTask` 的 `Flash_DumpAll` 之後、SD 卡初始化之前播放，代表系統初始化完成。過程中發現並修正 TIM2 ARR overflow bug：TIM2 為 32-bit timer，動態縮小 ARR 時若當下 CNT 已大於新的 ARR，計數器會一路數到 `0xFFFFFFFF`（約 4295 秒）才歸零，導致 buzzer 在第三聲後完全不響。修正方法為設定 ARR/CCR1 後立即寫入 `EGR = TIM_EGR_UG` 強制 update event，使 CNT 立刻歸零並套用新週期。

- **2026-05-27：printf 重定向 USART2 (115200 baud) 實現即時串口波形監控**
  - 實測結果：在 `main.c` 新增 `_write()` syscall 覆寫，將標準 `printf` 輸出重定向至 USART2（連接 ST-LINK 虛擬串口）。主迴圈每 50ms (20 Hz) 透過 UART 輸出 BMI088 加速度、ADXL375 高 G 加速度、BMP388 氣溫/氣壓/高度等共 9 個數值欄位的 CSV 格式串流，搭配 Serial Plotter / Python 腳本即可即時繪製 IMU 波形。每 1000ms 另輸出一次各感測器實際採樣率（`[RATE]` 格式），便於自動化測試斷言分析。

- **2026-05-27：採樣率監測模組 (Rate Monitor) 整合，全感測器實測 Hz 可視化**
  - 實測結果：新增獨立模組 `rate_monitor.h`，以巨集 `SAMPLING_RATE_DECL()` 宣告全域結構體 `g_sampling_rate`，包含 BMI088 加速度計、陀螺儀、ADXL375、BMP388 各通道的 `.rate_hz` 欄位。各中斷與任務分別呼叫 `RATE_TICK_BMI088_ACC()`、`RATE_TICK_BMI088_GYRO()`、`RATE_TICK_ADXL375()`、`RATE_TICK_BMP388()` 進行累加，模組每秒自動計算並更新真實物理採樣頻率。在 IDE Watch / Live Expressions 只需加入 `g_sampling_rate` 即可一次觀察全部感測器 Hz。可透過 `rate_monitor.h` 中 `#define RATE_MONITOR_ENABLE` 的有無開關整個功能，零停機代價。

- **2026-05-27：IWDG 獨立看門狗配置完成，更新為 2.0 秒快速超時以保障飛行安全**
  - 實測結果：配置 IWDG 使用 LSI 32 kHz 振盪器，16 分頻（計數頻率 2000 Hz），載入值 4095，超時時間精準設定為 **2.05 秒**。超短的超時時間可保障在火箭飛行中如遇強干擾死機時能以最快速度重啟。通過 FreeRTOS 將 SD 卡 / FatFs 磁碟讀寫等耗時任務完全隔離在 `DataLogging_Task`，主迴圈每個 `tick`（1 ms）均呼叫 `HAL_IWDG_Refresh()` 餵狗，保障系統高穩定性不誤復位。

- **2026-05-27：W25Q128 SPI Flash 啟動自檢與寫入校驗 100% 成功**
  - 實測結果：透過 SPI3 匯流排 (SCK=PB3, MISO=PB4, MOSI=PB5) 與 CS=PA15 成功讀取 W25Q128 JEDEC ID (`0xEF4018`)，完成 4KB Sector 0 擦除、61 字節頁寫入、逐字節讀回比對全數通過。驅動程式模組化設計，包含 `w25q128.h` / `w25q128.c`，實作寫使能、忙碌超時輪詢、頁寫入、連續讀取等完整 HAL SPI 阻塞傳輸 API。由於 SPI3 為獨立匯流排，與 SPI1 (ADXL375/BMP388) 和 SPI2 (BMI088) 完全無匯流排衝突。

- **2026-05-27：SD 卡 10 秒高頻數據日誌 (HIL_10S.CSV) 寫入與無卡插拔防卡死優化成功**
  - 實測結果：實現了在 MCU 啟動後自動延遲掛載 SD 卡，並進行為期 10 秒的 100 Hz CSV 高頻遙測日誌寫入（儲存至 `HIL_10S.CSV` 檔案中，包含系統 Tick、BMI088、ADXL375、BMP388 所有感測器數據）。在寫入 10 秒後安全關閉檔案並卸載磁碟。針對無實體 SD 卡插入的 HIL 測試場景，將 `SDIO_DET_Pin` (PD3) 引腳配置由 `GPIO_NOPULL` 優化為 `GPIO_PULLUP`，徹底避免了引腳浮空導致 MCU 假性插卡檢測，使系統無卡時能優雅跳過掛載與 `f_open` 寫入，保證串口遙測輸出的絕對流暢與穩定，零卡死！

- **2026-05-27：TIM6 + TIM7 定時器獨立中斷 + 雙緩衝區 (Ping-Pong Buffer) BMI088 加速度 1600 Hz & 陀螺儀 2000 Hz 測試成功**
  - 實測結果：配置硬體定時器 TIM6 觸發 1.6 kHz 中斷（只讀取 BMI088 加速度計並塞入 16 筆的 Ping-Pong 緩衝區），配置 TIM7 觸發 2.0 kHz 中斷（只讀取 BMI088 陀螺儀並塞入 20 筆的 Ping-Pong 緩衝區）。FreeRTOS 任務每 10ms (100Hz) 提取各自批次最新數據進行遙測。因為 SPI2 匯流排專用於 BMI088，無任何中斷-任務競爭衝突，完全免除軟體互斥鎖。實測加速度計與陀螺儀物理採樣頻率精準達到官方設計之最高物理上限：**加速度計 1600.0 Hz & 陀螺儀 2000.0 Hz**！

- **2026-05-27：TIM3 定時器中斷 + 雙緩衝區 (Ping-Pong Buffer) ADXL375 3200 Hz 測試成功**
  - 實測結果：利用硬體定時器 TIM3 觸發 3.2 kHz 中斷，在中斷內直接透過 SPI1 讀取 ADXL375 原始資料（耗時僅 5.6us），並存入 32 筆資料的 Ping-Pong 雙緩衝區。FreeRTOS 任務每 10ms (100Hz) 提取批次最新數據進行遙測，上下文切換開銷降低 96.8%。實測物理採樣頻率精準達到理論最高 **3200.0 Hz**！
  - 另外開啟 BMP388 至 200 Hz ODR，並加入 SPI1 總線互斥安全鎖，在讀取 BMP388 期間屏蔽 TIM3 中斷防止衝突。將系統 LED 翻轉減緩為溫和的 0.5 秒 (1 Hz) 心跳指示。

- **2026-05-25：頂層接口板 (Top Layer) -> Arduino 整合測試成功**
  - 測試結果：成功透過 Arduino (ESP32) 讀取 I2C 磁力計 (`MMC5983MA`) 與解析 UART2 GPS (`NEO-M9N`) 的實時同步數據流。所有實體走線與通信介面工作完美。
  - 目前狀態：等待首批 `BigAvionic` 板子打樣完成後，正式與 STM32 主控板進行韌體整合測試。

---

## 開發環境設定

### 1. 快速開始 (本地 IDE 輕量化 GCC 模式)

**必要工具鏈（已安裝）**：

- `arm-none-eabi-gcc` v16.1.0（透過 Homebrew 安裝於 `/opt/homebrew/bin/`）
- `arm-none-eabi-binutils` v2.46.0

**注意**：主晶片因缺料改用 **STM32F407VGT6**（Pinout 與 STM32F405VGT6 完全一致），氣壓計改用 **BMP388**（Pinout 與 BMP390 完全一致）。

### 2. 編譯步驟

1. 確認工具鏈在 PATH 中：
   ```
   arm-none-eabi-gcc --version
   ```
2. 執行編譯（使用 4 核心並行編譯）：
   ```
   make -j4
   ```
3. 編譯成功後，會在 `Main_AV_F407/Debug/` 目錄下自動產生以下執行與燒錄檔：
   - `bigav_407.elf` (用於除錯)
   - `bigav_407.hex` / `bigav_407.bin` (用於燒錄)

### 3. 一鍵燒錄與實體單步除錯

推薦在 IDE 中安裝 **Cortex-Debug** 擴充套件，並在專案根目錄 `.vscode/launch.json` 中配置 ST-LINK 除錯器，即可在 IDE 中按下 F5 實作 ST-Link 一鍵燒錄與中斷點除錯。

---

## 環境設定檢查

| 工具 | 狀態 | 版本 | 安裝路徑 |
|---|---|---|---|
| arm-none-eabi-gcc | 已安裝 | 16.1.0 | /opt/homebrew/bin/ |
| arm-none-eabi-binutils | 已安裝 | 2.46.0 | /opt/homebrew/bin/ |
| OpenOCD / ST-LINK | 待安裝 | - | - |

---

## 當前開發進度表 (TodoList)

進度追蹤提醒：每當您或團隊成員在進度表勾選完成項目（將 `[ ]` 改為 `[x]`）時，請務必在該項目後方標註實際完成日期（例如：`(2026-05-25 完成)`），以便精確掌控研發時程。

### 階段一：硬體設計與送印 (已完成)

- [x] 主航電四層板結構規劃 (`top`, `mainmcu`, `lora`, `newpower`) (2026-05-25 完成)
- [x] 開傘部署板完成佈局並導出 Gerber (2026-05-25 完成)
- [x] 設計二合一合併板 `Production_MCU_TOP_2_in_1` 以利成本最佳化 (2026-05-25 完成)
- [x] 完整解析 MCU、LoRa、Top、Power 原理圖 PDF，建立航電連線與基本硬體規格表 (2026-05-25 完成)
- [x] 完成 STM32CubeMX (.ioc) 核心 NVIC、DMA、FreeRTOS 與 FATFS 的硬核架構配置與交接規格書 (2026-05-26 完成)
- [x] **送印打樣**：聯絡工廠進行首批 5 張板子的製作打樣 (2026-05-25 完成)

### 階段二：樣板焊接與硬體除錯 (進行中)

- [ ] **上電短路檢測 (Safety Short-Circuit Check)**：確認各電源軌 (5V, 3.3V, VBAT) 無對地短路，防止燒毀主控與高價感測器。
- [x] 收到樣板：首批 5張核心電路樣板已製作完成並順利送回 (2026-05-25 完成)
- [ ] 樣板焊接：進行元件手工焊接與鋼網刷錫膏
- [ ] 電源軌測試：確認 5V/3.3V DCDC 降壓紋波與 LTC4412 理想二極體路徑切換正常
- [ ] 最小系統測試：確認 STM32F4 主控晶片燒錄，點亮 LED 並完成 GPIO 測試

### 階段三：軟韌體整合與射頻通訊聯調 (進行中)

- [x] **UART printf 串口重定向**：實作 `_write()` syscall 將 printf 重定向至 USART2，以 20 Hz CSV 即時輸出 IMU + 氣壓計數值，支援串口波形監控與 Python 自動化測試腳本 (2026-05-27 完成)
- [x] **採樣率監測模組 (rate_monitor.h)**：整合全感測器實測 Hz 可視化，`g_sampling_rate` 可在 IDE Watch 一次觀察所有感測器採樣率，每秒輸出一次 `[RATE]` 行 (2026-05-27 完成)
- [x] **IWDG 看門狗配置**：2.0 秒超時，提供飛行快速死機復位保護，配合 FreeRTOS 任務隔離防誤觸發，主迴圈每 1 ms 餵狗 (2026-05-27 完成)
- [x] **氣壓計高度計測試**：SPI 讀取 `BMP388` 數據，並在 200 Hz ODR 下實現 1x 過採樣穩定換算實時高度 (2026-05-27 完成)
- [x] **高頻定時器中斷與雙緩衝採樣測試 (ADXL375)**：實作 TIM3 3.2 kHz 中斷 + 雙緩衝 (Ping-Pong Buffer) 打包機制，讓 ADXL375 (High-G) 實測頻率精準達到 **3200 Hz** 理論最高極限，並加入 SPI1 總線互斥安全遮罩與將系統 LED 頻率降至 0.5s 一次 (2026-05-27 完成)
- [x] **高頻定時器中斷與雙緩衝採樣測試 (BMI088)**：實作 TIM6 1.6 kHz (加速度計) 與 TIM7 2.0 kHz (陀螺儀) 獨立中斷與雙緩衝 (Ping-Pong Buffer) 機制，實測頻率精準達到各自最高極限 **加速度計 1600 Hz & 陀螺儀 2000 Hz**，免除 SPI2 總線衝突與互斥鎖開銷 (2026-05-27 完成)
- [ ] **地磁計校準與 AHRS 姿態解算**：讀取 `MMC5983MA` 電子羅盤定位，並結合 BMI088 1.6kHz + 2.0kHz 高頻姿態數據流，實現 3D 姿態估算 (AHRS)
- [ ] **頂點偵測演算法 (Apogee Detection Algorithm)**：開發基於氣壓高度數據的卡爾曼濾波 (Kalman Filter) 算法，確保頂點判定精確且不受機艙噪聲干擾。
- [ ] **FSM 飛行狀態 Flash 備份與熱啟動自動恢復**：實作在 `init` 階段讀取 `W25Q128` Sector 0 的系統狀態旗標，在飛行中斷電重啟時自動空中熱接管 (Saved State 恢復)，並設計防重複部署安全鎖，徹底防止高G與開傘瞬間斷路引發的安全事故。
- [ ] **GPS 收星調試**：`NEO-M9N` 連續收星定位測試，驗證主動天線訊號強度
- [x] **SPI Flash 記錄測試**：實現 `W25Q128` 高速航電數據日誌 (Data Logging) 讀寫。完成 SPI3 匯流排驅動、JEDEC ID 驗證、4KB 扇區擦除、頁寫入與 100% 逐字節校驗 (2026-05-27 完成)
- [x] **Flash 環形緩衝區 (Ring Buffer) 實裝與 HIL 驗證**：在 `w25qxx.c` 實作完整環形緩衝區寫入機制。包含 52-byte packed 飛行數據封包（含 CRC-16/CCITT 校驗、magic bytes 0xAA 0x55、seq 滾動序號），開機二元搜尋恢復寫入頭（斷電後自動接續），預擦 10 個 Sector（40KB）以確保寫入區已清除，滾動擦除防止衝突。以 20 Hz 寫入速率，30 秒 HIL 測試寫入 461 筆封包（>400 門檻 ✅），Flash dump 驗證魔術字節與數據完整性 100% 通過 (2026-05-27 完成)
- [x] **SD 卡檔名自動遞增與立即掛載修復**：修正 SD 卡檔案命名邏輯，每次開機自動掃描 `HIL_001.CSV`～`HIL_999.CSV`，找到第一個不存在的序號並建立新檔，避免覆蓋上一次測試數據。同時修正 `f_mount` 由延遲掛載 (opt=0) 改為立即掛載 (opt=1)，解決首次 `f_stat` 回傳 `FR_NOT_READY`（錯誤碼 3）導致建立檔案失敗的問題 (2026-05-27 完成)
- [x] **採樣率延遲評估修正（FlashRing_Init 後重置計數器）**：`FlashRing_Init()` 預擦 10 個 Sector 阻塞約 2 秒，期間 BMP388（主迴圈讀取）無法累積計數，導致首報 Hz 嚴重低估（171 Hz 而非實測 ~196 Hz）。解法：`FlashRing_Init()` 完成後立即呼叫 `SAMPLING_RATE_INIT()` 重置所有感測器計數器，確保 `[RATE]` 報告反映穩態採樣率 (2026-05-27 完成)
- [x] **Buzzer 開機提示音**：TIM2 CH1 PWM 實作開機兩聲漸高提示音（2 kHz → 4 kHz），並修正 TIM2 32-bit ARR overflow 導致 buzzer 停響的 bug（`EGR = TIM_EGR_UG` 強制歸零 CNT）(2026-06-01 完成)
- [x] **SD 卡全程記錄（FSM 驅動）**：移除原 10 秒上限，改為全程記錄——升空至落地前 100 Hz，落地後（新增 `g_touchdown_tick` 標記，非 `STATE_LANDED` 進入點）降為 10 Hz 繼續記錄，由 USER_BT1 或落地逾時（`SD_LANDED_LOG_TIMEOUT_MS`，預設 30 分）停止並安全關檔。CSV 新增 `fsm` / `ekf_alt_cm` / `ekf_vel_cms` 欄位，每秒 `f_sync` 限制斷電遺失。移除落地 `vTaskSuspend`，使遙測 / Flash ring / 尋標蜂鳴器於落地後持續運作 (2026-06-01 完成)
- [x] **GPS 驅動實作（USART6 NMEA-0183）**：自包含 NMEA 解析器（`gps.c` / `gps.h`），解析 GGA（定位品質/衛星數/海拔）與 RMC（定位/地速/航向/有效性），XOR checksum 驗證、`ddmm.mmmm` 經緯度換算（×1e6 deg）、knots→m/s。RX 採 USART6 循環 DMA + IDLE-line（`HAL_UARTEx_ReceiveToIdle_DMA`，事件回呼以 old_pos 差分取出新位元組組句、僅設旗標），解析於主迴圈 task context 進行避免 ISR 內繁重字串處理；`HAL_UART_ErrorCallback` 處理 overrun 自動重啟 DMA RX。256-byte DMA 緩衝置於主 SRAM（0x20000150，DMA2 可存取，非 CCM）。有效定位之經緯度填入 Flash ring buffer，新增 1 Hz `[GPS]` 遙測行（fix/衛星數/經緯度/海拔/地速/stale/解析統計）。**過程中發現並修正計畫書 GPS/LoRa 的 UART 對應顛倒**（詳見修訂紀錄）(2026-06-01 完成，待硬體收星驗證)
- [x] **地磁計驅動（MMC5983MA, I2C1）**：自包含驅動 `mmc5983.c` / `mmc5983.h`，I2C1 位址 0x30，18-bit one-shot 量測（TM_M 觸發 + STATUS 輪詢 + 三軸 18-bit 組裝）；SET/RESET 雙極性量測消除橋式偏移（`offset=(set+reset)/2`，量測後留 SET 極性供快速單次讀取）；開機 ProductID（0x30）驗證、`gauss`/heading 換算（16384 LSB/Gauss）、`[MAG]` 1 Hz 遙測、發射台階段每 10 s 自動重校 (2026-06-02 完成，待硬體驗證軸向)
- [x] **GPS 水平位置（E/N）融入 EKF**：發射台第一筆有效定位鎖定原點（lat0/lon0），等距投影換算 ENU 水平位移，以 Joseph-form 標量量測更新套用於 E/N 兩軸，量測噪聲 R 隨衛星數縮放（≥8→6.25 / ≥6→25 / ≥4→100 / else 2500）；**僅飛行中融合**（發射台因 ZUPT 歸零水平狀態而捨棄），高度仍交由氣壓計 (2026-06-02 完成，待 HIL 驗證)
- [x] **地磁計航向（yaw）融入 EKF**：Mahony 傾斜補償互補修正，水平磁場參考投影至 ENU-East（`bx=√(hx²+hy²)`, `bz=hz`, by=0）使其僅約束航向；body 預測磁場 `w=Rᵀ·b`、誤差 `e=m×w` 以陀螺修正積分（Kp_mag=1.0, dt=0.1s）；**僅發射台階段**（校準後、未升空）鎖定絕對航向、抑制陀螺 yaw 漂移，升空後純陀螺遞推 (2026-06-02 完成，待 HIL 驗證軸向/增益)
- [x] **EKF 狀態跨任務原子讀取（改善項目 O）**：`EKF_GetState()` 以 `taskENTER_CRITICAL` 封住對 `EKF_x`/`EKF_q`/`EKF_accel_bias` 的拷貝，修正 EKF_Task（High）搶佔 defaultTask（Normal）讀取時的撕裂讀取（位置/速度跨輪不一致）(2026-06-02 完成)
- [x] **ADXL375 解析死碼清理（改善項目 M 部分）**：移除 `ADXL375_ReadData` 中以錯誤索引（`z_raw` 用 `rx_data[4]`）解析後又被正確碼覆蓋的死碼，補 byte-map 註解並釐清軸向約定（與 BMI088 一致：驅動層輸出感測器原生軸、反向修正集中於 EKF）(2026-06-02 完成)
- [x] **Flash 寫入速率 FSM 分級（改善項目 F）**：ring buffer 由固定 20Hz 改為 INIT/PAD 20Hz、飛行（BOOST..MAIN_DEPLOY）50Hz、LANDED 1Hz；飛行率取 50Hz 而非 100Hz，因 `FlashRing_WritePacket` 內含同步滾動 sector 擦除（最壞 ~400ms 阻塞）會卡住感測器/EKF 饋入，全速需先做 G(2026-06-02 完成)
- [ ] **LoRa 無線拉距通訊**：使用 BigAvionic 作為地面站接收端，進行公里級發射接收封包損耗測試
- [ ] **SPI 共用總線單點故障隔離與超時保護**：在 W25Qxx 與 LoRa E80 的 SPI 讀寫/忙碌等待中引入計數器軟體超時保護；若 ID 校驗失敗或連續超時，自動將設備標記為離線（degraded）並跳過該設備後續的 SPI 讀寫與 `g_spi3_mutex` 鎖定，避免單點硬體故障（如 MISO 接地）拖垮整個 SPI3 總線與共用任務。

### 階段四：開傘安全與地面引爆測試 (待啟動)

- [ ] **引爆迴路導通檢測 (Continuity Check)**：測試 `Deployment board` 的安全監測電路，確保能透過微弱電流精確判斷火工品引信是否導通，同時不觸發引爆。
- [ ] **安全保險開關 (Arming Switch) 邏輯驗證**：驗證實體保險開關，確保地面上電前完全斷開，火箭解鎖後才允許高壓驅動。
- [ ] **火工品地面點火模擬測試 (Ground E-Match Firing Test)**：在戶外安全環境下，進行實體火工品 (E-Match) 電子點火觸發測試，確認 DCDC 開關電源不會因瞬間大電流而崩潰。

### 階段五：環境適應性與可靠度模擬測試 (待啟動)

- [ ] **真空艙氣壓高度測試 (Vacuum Chamber Altimeter Test)**：將組裝好的航電艙置於真空艙中，進行快速抽氣與放氣以模擬火箭起飛與降落，驗證高度計數據讀取與雙階段開傘觸發時機是否精確。
- [ ] **抗震與硬體抗噪測試 (Vibration & Noise Check)**：在模擬火箭發動機燃燒的震動環境下測試感測器，確認噪聲不會引發頂點誤判定，並驗證實體接線抗震可靠度。
- [ ] **高低溫電池效率測試 (Thermal & Battery Test)**：測試低溫環境下（模擬高空環境），板載鋰電池的放電效率與電壓穩定性。

### 階段六：整機整合與發射全系統模擬演練 (待啟動)

- [ ] **航電艙整機裝配 (Avionics Bay Integration)**：完成多層疊板結構物理鎖緊、天線固定、防風防強光影響的氣壓艙孔結構設計。
- [ ] **實時遙測上位機 Dashboard 聯調**：地面接收端 (`BigAvionic`) 與電腦上位機連線，實時接收封包並在 GUI 繪製即時高度、3D 姿態與地圖 GPS位置。
- [ ] **發射前倒數 SOP 演練 (Launch Countdown SOP)**：從航電艙上電、自檢 (Self-Test)、GPS 定位確認、保險上膛 (ARM)、發射倒數點火的完整流程演練，確保發射當天零失誤。

---

## 重要修訂紀錄

- **2026-06-01（改善項目實作 #1）**：依改善計畫（`context-rosy-kahan.md`）實作三項低風險項目，皆通過 STM32CubeIDE 工具鏈編譯。
  - **D — FPU context save 確認（無需修改）**：FreeRTOS 採 `ARM_CM4F` port + 編譯旗標 `-mfloat-abi=hard`（`__FPU_USED=1`，`SystemInit` 已設 CPACR）。`port.c` 於 `xPortStartScheduler` 呼叫 `vPortEnableVFP()` 並設定 `FPCCR` 的 `ASPEN|LSPEN`（硬體 lazy FPU context 保存），PendSV 依 EXC_RETURN 自動保存 S0–S31/FPSCR。`FreeRTOSConfig.h` 的 `configENABLE_FPU 0` 僅 ARMv8-M（CM23/CM33）port 會讀取，於 M4F 無作用——故 EKF 浮點運算在任務切換時本就安全。
  - **I — EKF queue drop 計數（觀測先行）**：`osMessageQueuePut` 失敗時遞增 `g_ekf_queue_drops`，於 `[RATE]` 行新增 `EKF_DROP` 欄位輸出。釐清一個計畫原稿的隱患：EKF queue 傳遞的是 **2 槽 ping-pong buffer 指標**（`g_ekf_buffers[2]`，索引以 `!idx` 切換），若僅把 queue 深度擴大到 8 而不同步擴大實體 buffer pool，會造成 stale-pointer 覆寫；且實測 `bss` 已達 ~113 KB / 128 KB SRAM，擴大為 8 buffer（+~22 KB）會溢位。故先計數觀測，確認確實有 drop 再評估「擴 pool + 改 modulo-N 索引 + 移入 CCM」。
  - **N — Flash dump 改條件觸發**：開機 `Flash_DumpAll(&hspi3)` 改為僅在按住 `USER_BT1`（上拉輸入，按下 = LOW）時執行，平時開機省下整顆 Flash 輸出的 ~3–5 秒。
  - **暫緩（需硬體在環驗證）**：🔴 A（ADXL375 融入 EKF 高 G 相位，飛行關鍵融合變更）、B（SPI1 mutex；因 ADXL375 目前於 TIM3 ISR 內讀取，mutex 不可用於 ISR，需先將讀取改為「ISR notify → task 讀取」，屬 3.2 kHz 採樣路徑重構）。建議於可上板測試的 session 進行。

- **2026-06-01（改善項目實作 #2）**：續做兩項功能完善，皆通過工具鏈編譯（無警告）。
  - **E — SD 卡 FSM 驅動全程記錄**（`5e7cd2f`）：移除原開機 10 秒上限——飛行全程 100 Hz、落地後降 10 Hz 持續記錄；新增 `g_touchdown_tick` 標記（落地是 `STATE_LANDED` 內的子條件，非進入點）；停止條件為按 `USER_BT1` 或落地逾時 `SD_LANDED_LOG_TIMEOUT_MS`（預設 30 分）後安全關檔；CSV 新增 `fsm` / `ekf_alt_cm` / `ekf_vel_cms` 三欄；每秒 `f_sync` 限制斷電遺失。移除原落地 `vTaskSuspend(NULL)` 與內嵌關檔，使遙測 / Flash ring / 尋標蜂鳴器於落地後仍持續運作。
  - **H — 氣壓高度溫度補正**（`76c55b7`）：將 `bmp388.c` 的高度換算由 ISA 定溫公式 `44330·(1-(P/P0)^0.190295)`（固定假設 15 °C）改為 hypsometric 等溫層公式 `h = (R/g)·T0·ln(P0/P)`，並於開機自檢時取 16 筆 BMP388 溫度平均、以 `BMP388_SetReferenceTemp()` 鎖定發射台 T0（範圍檢查 −40~85 °C，否則維持 288.15 K）。**關鍵安全設計**：T0 在 EKF 校準（RTOS 啟動後 3 秒平均）之前即鎖定且全程固定，使 EKF 的 launchpad 參考與飛行讀數共用同一 T0 → 相對高度於發射台恆為 0 且全程連續，校準完成瞬間無階躍，故不影響 FSM 頂點偵測。參考氣壓 `P0`（101325 Pa）在相對高度相減時完全抵銷，真正影響尺度的是 T0；於預設 288.15 K 時與原公式的壓-高靈敏度差 < 0.03%（0.08324 vs 0.08326 m/Pa），高溫環境則正確放大實際高度尺度（避免主傘觸發高度與頂點高度被低估）。開機自檢讀取 BMP388（SPI1）時同步暫關 TIM3 中斷，避免與 ADXL375 的匯流排競爭。

- **2026-06-01（改善項目實作 #3：A+B 設計文件）**：產出 `設計_ADXL375_EKF融合與SPI1並發.md`，**不含飛行碼變更**，供可上板 / HIL session 實作 🔴 A、B。文件含程式碼定位、設計、code 草圖與上板驗證清單。盤點時發現**前置阻斷項**：EKF 加速度單位不一致——BMI088 樣本為 g（`bmi088.c:162`，`×24/32768`），但 `EKF_Predict`（`ekf.c:202`）以 m/s² 減去 `GRAVITY=9.80665` 並積分；靜置由校準強制抵銷（故 ZUPT/bench 靜態正常），但**動態加速度被低估約 9.81×**。ADXL375 同為 g（`adxl375.c:108`），故須先統一單位（建議全程 m/s²，`×9.80665`）才有意義融合，此即 A 必須 HIL 驗證的根因。B 釐清「FreeRTOS mutex 不可用於 ISR」（ADXL 現於 TIM3 ISR 讀 SPI1），建議先正規化現有「暫關 TIM3 IT」臨界區為 `SPI1_Lock/Unlock()` helper（B1），DMA 驅動（B3）列長期。

- **2026-06-01（改善項目實作 #4-J：GPS 驅動）**：實作自包含 NMEA-0183 驅動 `gps.c` / `gps.h`，通過工具鏈編譯（無警告）。
  - **解析**：GGA（fix 品質 / 衛星數 / 海拔 / 大地水準面分離）與 RMC（狀態 A/V / 地速 / 航向）；XOR checksum 驗證；`ddmm.mmmm`/`dddmm.mmmm` 手動換算為 deg×1e6（int32，以 double 縮放保有效位）；knots→m/s（×0.514444）；句型比對忽略 talker ID（GP/GN/GL...）。`GPS_Update()` 於主迴圈 task context 解析（每迴圈呼叫，無資料時僅檢查旗標），`GPS_GetData()` / `GPS_IsStale()` 對外只讀。
  - **接收路徑**：採 USART6 循環 DMA（DMA2_Stream1, ch5）+ IDLE-line（`HAL_UARTEx_ReceiveToIdle_DMA`）；`HAL_UARTEx_RxEventCallback` 以 `old_pos` 差分取出新位元組餵入 line-assembly，僅做位元組搬移與設旗標（ISR-safe，不呼叫 FreeRTOS API）。256-byte DMA 緩衝經 `.map` 確認落於主 SRAM `0x20000150`（DMA2 可存取，非 CCM）。`HAL_UART_ErrorCallback` 於 overrun 清旗標並重啟 DMA RX，避免 RX 死掉。
  - **整合**：有效定位之經緯度填入 Flash ring buffer 的 `gps_lat`/`gps_lon`（原全填 0）；新增 1 Hz `[GPS]` 遙測行（正負號 + 絕對值列印避開「整數部為 0 卻為負」遺失負號的陷阱）。
  - **🔧 修正計畫書 UART 對應錯誤（飛行硬體關鍵）**：計畫 `context-rosy-kahan.md` 與初版 `gps.h` 誤將 GPS 標為 USART3。對照硬體金標準 `連線和基本硬體規格表.md`（自原理圖 100% 萃取）確認：**GPS(NEO-M9N) 實體為 USART6（PC6=TX/PC7=RX，已配置循環 DMA RX），USART3(PD9) 實為 E22-400T30S 433MHz LoRa**。原 2026-05-26 紀錄的「USART6 GPS、USART3 LoRa」才正確。若照計畫接到 USART3，GPS 將永遠收不到資料且會與 LoRa 模組搶線。已全面改為 USART6 並採其既有 DMA 配置（與 USART2 遙測 DMA-circular 同模式）。
  - **待硬體驗證**：上板接 NEO-M9N，確認 `[GPS]` 行 fix→1、衛星數遞增、經緯度合理（成大約 N22.9°, E120.2°）。

- **2026-06-02（改善項目實作 #5/#6/#7：地磁計驅動 + GPS/地磁計融入 EKF）**：實作 MMC5983MA 驅動並將 GPS 水平位置與地磁計航向融入 EKF，三項皆通過工具鏈編譯（最終 ELF text=131864，無新增警告）。
  - **#5-L 地磁計驅動（`ace8625`）**：自包含 `mmc5983.c` / `mmc5983.h`。I2C1（`hi2c1`，400 kHz；STM32F407 矽晶 AF mux 強制 PB7=SDA/PB8=SCL，文件「SCL=PB7」僅命名、HAL 自動處理，驅動與接腳標號無關），7-bit 位址 0x30。流程：`IsDeviceReady` → ProductID（0x2F 應回 0x30）→ SW reset（CTRL1 0x80）+ 15 ms → BW_400HZ → 初次 SET/RESET 橋偏自校。量測：TM_M（CTRL0 0x01）觸發 + STATUS（0x08）MEAS_M_DONE 輪詢（10 ms timeout），讀 XOUT0 起 7 byte 組裝 18-bit（`(raw0<<10)|(raw1<<2)|((raw6>>shift)&0x3)`，X/Y/Z shift=6/4/2），零點 131072（2^17）、16384 LSB/Gauss。SET/RESET 消除橋式偏移後留 SET 極性供快速單次讀取。主迴圈每 100 ms 讀一次並 `EKF_SubmitMag`，發射台階段每 10 s `MMC5983_Recalibrate()`，新增 1 Hz `[MAG]` 遙測。
  - **#6 GPS → EKF（`ddbdd3c`）**：等距投影（about-launchpad equirectangular，`dN=Δlat·DEG2RAD·R`、`dE=Δlon·DEG2RAD·R·cos(lat0)`，R=6378137 m），E/N 兩軸各做一次 Joseph-form 標量量測更新（鏡像氣壓更新路徑），R 隨衛星數縮放。`EKF_SubmitGPS` 於發射台第一筆有效定位鎖定原點（`coslat0=cos(lat0)`），之後換算 ENU 水平位移、`taskENTER_CRITICAL` 發布單筆待處理量測（多次提交僅保留最新）。**僅 `EKF_in_flight` 時套用**——發射台 ZUPT 每樣本歸零水平狀態，pad 定位無意義故捨棄；高度保留給氣壓計。
  - **#7 地磁計 → EKF（`0ad175d`）**：Mahony 傾斜補償 yaw 互補修正，完全比照 EKF **既有旋轉慣例**（R 為 body→nav，重力/上方向 = R 第三列 `[r31,r32,r33]`）。將參考磁場水平分量塌縮至 nav-East（`bx=√(hx²+hy²)`、`bz=hz`、by=0）使其**僅約束航向**；body 預測磁場 `w=Rᵀ·b`（`wx=r11·bx+r31·bz`…），誤差 `e=m×w` 當作陀螺修正積分入四元數（Kp_mag=1.0，dt=0.1 s）。**僅 `EKF_calibrated && !EKF_in_flight`（發射台階段）套用**，鎖定絕對航向並抑制重力回授無法觀測的陀螺 yaw 漂移；升空後純陀螺遞推（與既有設計一致）。
  - **⚠️ 待 HIL 實機驗證（飛行關鍵）**：(1) 磁力計三軸須與 IMU body frame 對齊——bench 測試若發現航向往反向收斂，於 `main.c` 呼叫端對相應軸取負號即可（已於 `EKF_SubmitMag` 註解標記）；(2) `Kp_mag` 與 GPS 量測噪聲 R 需依實測噪聲調參；(3) GPS 原點鎖定時機（第一筆 post-calibration fix）需確認收星穩定後才鎖。融合邏輯（pad-only mag、flight-only GPS、旋轉慣例）已於程式碼定型，調參與軸向為上板項。

- **2026-06-02（改善項目實作 #8-O / #9-M(部分) / #10-F：併發安全、死碼清理、寫入速率分級）**：三項軟體層改善，皆通過工具鏈編譯（ELF text=131864，僅餘 `ekf.c` 既有的 `EKF_PrintFloat('\r\n')` multichar 警告，非本次新增）。
  - **O — EKF 狀態原子讀取（`478329a`）**：`EKF_GetState()`（`ekf.c:483`）原以無保護方式逐欄拷貝 `EKF_x[6]` 並 `memcpy` `EKF_q`/`EKF_accel_bias`。但 EKF_Task（osPriorityHigh）持續寫入這些狀態，defaultTask（Normal）於 `[TELE]` 遙測（`main.c:1367`）、FSM 動態頂點判斷、SD 記錄（`main.c:1667`）三處呼叫讀取——High-prio 任務可在拷貝中途搶佔，使回傳的 state「位置取自舊一輪、速度取自新一輪」。以 `taskENTER_CRITICAL/taskEXIT_CRITICAL` 封住拷貝（純記憶體搬移，數十週期，對中斷延遲影響可忽略），保證一致快照。EKF_Task 內部第 768 行亦呼叫本函式（同任務），FreeRTOS 臨界區計數可巢狀，安全。**釐清**：`imu_data`/`highg_data`/`baro_data` 雖也是全域結構，但實為 defaultTask 單一任務讀寫（EKF 經 ping-pong buffer + queue 傳遞，不直接讀這些結構），故無跨任務撕裂風險，O 真正的標的是 `EKF_GetState`。
  - **M(部分) — ADXL375 解析死碼清理（`3266a0b`）**：`ADXL375_ReadData` 原先以**錯誤索引**解析一次三軸（`z_raw` 誤用 `rx_data[4]` 而非 `rx_data[5]`），緊接著又以正確索引重算覆蓋——前者為死碼且具誤導性（若日後誤刪後段正確碼即引入真 bug）。移除死碼、補 byte-map 註解。**刻意不做計畫原稿的軸向 sign-flip**：經查 BMI088（`bmi088.c:162`）同樣於驅動層輸出感測器原生軸，X/Y 反向修正集中在 EKF；故目前 Flash log 內 ADXL 與 BMI 的 raw 皆為感測器原生座標、約定本就一致，單獨對 ADXL 取負反而會破壞一致性。日後 ADXL 融入 EKF（改善項目 A）時於 EKF 饋入處比照 BMI088 取負即可，註解已標明。
  - **F — Flash 寫入速率 FSM 分級（`0a03cf8`）**：ring buffer 由固定 20Hz 改為依 `current_fsm_state`：INIT/PAD 20Hz、飛行各相位（BOOST..MAIN_DEPLOY）50Hz、LANDED 1Hz。**飛行率取 50Hz 而非計畫原稿的 100Hz** 是經分析的安全取捨：`FlashRing_WritePacket`（`w25qxx.c:527`）含「同步」滾動 sector 擦除（W25Q128 4KB sector 最壞 ~400ms、典型 ~45ms 阻塞），會卡住主迴圈的感測器批次提取與 EKF 饋入；50Hz 下擦除約每 1.56s 一次（4096B/52B≈78 筆/sector），與現行 20Hz 的 3.9s 同數量級、屬已驗證可接受範圍；100Hz 則 0.78s 一次、阻塞密度過高。要安全全速須先做 G（擦除移獨立低優先任務）。亦未在此擴充 binary 封包 EKF 欄位（會破壞既定 52-byte 格式與 CRC、開機二元搜尋恢復），EKF 估算高度/速度已在 SD CSV（改善項目 E）記錄。
  - **本批暫緩項與理由**：🔴 **A**（ADXL 融入 EKF）需先修 EKF 加速度單位不一致（g↔m/s²，見 #3 設計文件）並上板 HIL；🔴 **B**（SPI1 mutex）需把 ADXL 從 TIM3 ISR 內讀取重構為「ISR notify → task 讀取」（mutex 不可用於 ISR），屬 3.2kHz 採樣路徑改寫，須上板驗證——兩者設計已備於 `設計_ADXL375_EKF融合與SPI1並發.md`。🟡 **G**（擦除移獨立任務）會引入 erase-task 與 write-path 對 SPI3 的並發，必須先有 **C**（SPI3 mutex 骨架），且優先權/優先反轉行為須上板量測，故 C+G 同批做較妥。🟢 **K**（LoRa E22 透傳遙測）需實體模組、M0/M1 模式腳與 AUX 流控、透傳封包格式，盲寫無法驗證。以上於可上板 session 進行。

- **2026-06-01**：新增 Buzzer 開機提示音（兩聲漸高 2 kHz → 4 kHz，TIM2 CH1 PWM）。修正 TIM2 32-bit ARR overflow 導致第三聲後 buzzer 完全停響的 bug（縮小 ARR 時 CNT 若大於新 ARR 需等 `0xFFFFFFFF` 才歸零，解法為 `EGR = TIM_EGR_UG` 強制 update event 即時歸零 CNT）。同步修正 `main.c` line 262 舊注解錯誤（W25Q128 Flash 為 SPI3 而非 SPI1）。完成航電系統全面技術盤點並建立改善計畫（含 SPI mutex 保護、ADXL375 融入 EKF 高G相位、SD 卡 FSM 驅動全程記錄、Sector erase 移至獨立任務、氣壓高度溫度補正等），詳見 `context-rosy-kahan.md`。(2026-06-01 完成)

- **2026-05-27**：完成 Flash 環形緩衝區 (Ring Buffer) 完整實裝與 HIL 自動化驗證。新增 `FlashRing_Init()`（開機二元搜尋恢復寫入頭 + 預擦 10 Sector）、`FlashRing_WritePacket()`（52-byte packed 封包、CRC-16/CCITT、滾動擦除）。30 秒 HIL 測試寫入 461 筆，Flash dump 驗證 magic bytes 0xAA 0x55 與數據完整。修正 SD 卡 `f_mount` 改為立即掛載解決 FR_NOT_READY 問題；修正 SD 卡 `f_stat` 邏輯實現 HIL_001.CSV → HIL_002.CSV 自動遞增。修正 `FlashRing_Init()` 後呼叫 `SAMPLING_RATE_INIT()` 重置計數器，確保第一個 `[RATE]` 報告反映穩態採樣率而非含暖機期的低估值。

- **2026-05-27**：新增 `_write()` syscall 將 printf 重定向至 USART2（115200 baud），主迴圈以 20 Hz CSV 格式輸出所有感測器即時數值，並整合 `rate_monitor.h` 模組以每秒 `[RATE]` 行回報各感測器實測 Hz；IWDG 看門狗設定為 2.0 秒超時（提供快速死機復位保護），主迴圈每 1 ms 定期餵狗。(2026-05-27 完成)
- **2026-05-27**：完成 W25Q128 SPI Flash 驅動開發與硬體迴路驗證。實作模組化 HAL SPI 驅動 (`w25q128.h`/`w25q128.c`)，包含 JEDEC ID 讀取、Power-Down 釋放、4KB Sector Erase、Page Program (≤256B)、連續讀取，以及帶超時保護的 WaitBusy 忙碌輪詢。首次嘗試使用 SPI1 匯流排失敗（JEDEC ID 回傳 `0x000000`），經用戶更正後確認 W25Q128 掛載於 **SPI3** (SCK=PB3, MISO=PB4, MOSI=PB5, CS=PA15)，切換後立即成功讀取 JEDEC ID `0xEF4018`，寫入測試字串並完成 100% 逐字節校驗。(2026-05-27 完成)
- **2026-05-27**：實作 BMI088 加速度計與陀螺儀獨立頻率採樣。TIM6 1600 Hz 中斷讀取加速度計（搭配 16 筆資料雙緩衝），TIM7 2000 Hz 中斷讀取陀螺儀（搭配 20 筆資料雙緩衝）。全面移除了 SPI2 在任務層的呼叫，由兩個中斷完全獨佔，提供高實時與零匯流排鎖定衝突的雙定時器高性能架構，實測採樣率分別高精準鎖定在 1600 Hz 與 2000 Hz。(2026-05-27 完成)
- **2026-05-27**：完成高頻定時器中斷 (Timer ISR) + 雙緩衝 (Ping-Pong Buffer) 的飛控級採樣架構優化。將 ADXL375 設定為 3200Hz ODR 並在中斷中直接讀取，實測採樣率完美達到 3200.0Hz 理論最高極限。降低 RTOS 切換開銷 96.8%（3200Hz 降至 100Hz）。解決 SPI1 總線在 TIM3 中斷與 FreeRTOS (BMP388 @ 200Hz) 之間的衝突問題，實作中斷屏蔽鎖。優化狀態反饋，將 system LED 擺動減慢為 0.5 秒 (1 Hz) 一次溫和視覺心跳。(2026-05-27 完成)
- **2026-05-26**：完成主航電 STM32F4 飛控底層配置。完成 STM32CubeMX (`.ioc`) 最終配置與硬體架構交接規格書。確立 NVIC 中斷優先級防禦線（FreeRTOS SYSCALL 優先級為 5），妥善配置 DMA 搬運通道（SDIO、USART2 雙機同步、USART6 GPS、USART3 LoRa）與 FreeRTOS (CMSIS_V2) + FATFS 中間件整合，為系統奠定堅實的實時多任務安全底座。(2026-05-26 完成)
- **2026-05-25**：首批五張樣板順利到貨。包含 `newpower`、`lora`、`mainmcu`、`top`、`Deployment board` 共五張核心電路樣板製作打樣圓滿完成，板子已順利運抵實驗室，硬體送印階段正式宣告 100% 達成。(2026-05-25 完成)
- **2026-05-25**：硬體規格與引腳連線完美解析。成功完成四層原理圖 PDF 檔案的 100% 完整解析，萃取出 STM32F407VGTx 的 100 支物理引腳實體 PCB 連線（Net Label），並建立繁體中文 `連線和基本硬體規格表.md` 黃金參考手冊。主晶片因缺料改用 STM32F407VGT6（Pinout 與 F405 完全相容），氣壓計因缺料改用 BMP388（Pinout 與 BMP390 完全相容）。(2026-05-25 完成)
- **2026-05-25**：完善長期開發里程碑。新增了極具航空航天工程標準的「地面安全與引爆測試」、「真空艙氣壓高度仿真測試」、「整機抗震驗證」與「發射前 SOP 演練」等關鍵里程碑，建構完整的航電全生命週期開發路線。
- **2026-05-25**：硬體測試里程碑。頂層接口板 (Top Layer) 成功與 Arduino 整合測試，順利實現磁力計與 GPS 的非阻塞式雙重數據同步。目前正等待發廠打樣，並進入 STM32 韌體整合準備。
- **2026-05-25**：專案架構重大重構。確立 5 板送印策略；副航電板與地面站分別改由 `mcu layer` 與 `BigAvionic 疊板` 代替。將 `Production_MCU_LORA_2_in_1` 二合一板正名為 `Production_MCU_TOP_2_in_1`，完美反映硬體架構（Top + MCU）。

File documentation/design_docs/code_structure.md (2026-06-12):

# 🚀 RocketCup 航電主控系統軟體架構與代碼結構規範書
## (Avionics Firmware Architecture & API Specification)

---

## 1. 系統時脈與感測器採樣率配置 (Sensor Sampling Rates)

為維持高可靠性之飛行狀態估算，系統實施了多匯流排隔離與非對稱高頻採樣。高頻 IMU 數據（BMI088 與 ADXL375）完全透過定時中斷與 Ping-Pong 雙緩衝進行背景資料收集，徹底免除飛控任務的等待時間。

```
+------------------+------------------+-------------------+--------------------------------------------+
| 感測器 (Sensor)  | 通訊匯流排 (Bus)  | 採樣頻率 (Rate)   | 中斷與資料讀取機制 (Trigger & Buffer)      |
+------------------+------------------+-------------------+--------------------------------------------+
| **ADXL375**      | SPI1 (Shared)    | **3200 Hz**       | TIM3 定時中斷觸發 SPI 讀取，推入 3.2kHz 雙緩衝區  |
| **BMI088 Accel** | SPI2 (Dedicated) | **1600 Hz**       | TIM6 定時中斷觸發 SPI 讀取，推入 1.6kHz 雙緩衝區  |
| **BMI088 Gyro**  | SPI2 (Dedicated) | **2000 Hz**       | TIM7 定時中斷觸發 SPI 讀取，推入 2.0kHz 雙緩衝區  |
| **BMP388**       | SPI1 (Shared)    | **200 Hz**        | TIM2 定時中斷觸發，具備 SPI1 總線屏蔽保護鎖  |
| **MMC5983MA**    | I2C1 (Shared)    | **100 Hz**        | PB7/PB8 I2C1 軟體定時任務背景查詢讀取       |
| **NEO-M9N GPS**  | UART6 (Dedicated)| **10 Hz**         | UART6 DMA 雙緩衝接收，空閒中斷 (IDLE) 背景解析|
+------------------+------------------+-------------------+--------------------------------------------+
```

### 1.1 SPI1 共享總線屏蔽鎖設計 (Bus Mutex Line Lock)
* **硬體背景**：ADXL375 (3.2kHz) 與 BMP388 (200Hz) 共享 SPI1。
* **衝突防範**：由於 ADXL375 之中斷頻率極高（每 312.5 微秒觸發一次），當 FlightControl_Task 正在讀取 BMP388（耗時約 250 微秒）或寫入 Flash 時，若 TIM3 中斷強行插入並發起 SPI1 交易，將直接導致 SPI 總線衝突與資料錯亂。
* **韌體實作**：在 FlightControl_Task 讀取 BMP388 暫存器期間，採用**硬體中斷暫時屏蔽線**：
  ```c
  void BMP388_Read_Safe(uint8_t reg_addr, uint8_t *data, uint16_t len) {
      __disable_irq(); // 暫時關閉全域中斷 (屏蔽 TIM3 插入)
      HAL_GPIO_WritePin(GPIOA, GPIO_PIN_4, GPIO_PIN_RESET); // 拉低 Baro CS
      HAL_SPI_TransmitReceive(&hspi1, &reg_addr, data, len, 10);
      HAL_GPIO_WritePin(GPIOA, GPIO_PIN_4, GPIO_PIN_SET);   // 拉高 Baro CS
      __enable_irq();  // 恢復全域中斷
  }
  ```

---

## 2. 卡爾曼濾波 (Kalman Filter) 融合與實時飛控時序

飛控核心任務 `FlightControl_Task` 以 **100 Hz (10ms 週期)** 穩定運行。在每一個 10ms 週期內，系統精確進行**「降採樣濾波」**與**「卡爾曼更新」**：

```
時序軸 (Time line - 10ms 週期)
|---------------------------------------------------------------------------> 10ms
TIM3 ISR (3.2kHz) [||||||||||||||||||||||||||||||||] -> 採樣 ADXL375 共 32 筆數據
TIM6 ISR (1.6kHz) [||||||||||||||||]                 -> 採樣 BMI_Acc 共 16 筆數據
TIM7 ISR (2.0kHz) [||||||||||||||||||||]             -> 採樣 BMI_Gyro 共 20 筆數據
TIM2 ISR (200Hz)  [|]                                -> 採樣 BMP388 共 2 筆數據

FlightControl_Task 喚醒 (10ms 邊界)
 ├── 1. 切換雙緩衝區 (Ping-Pong Switch)，保證中斷可繼續無鎖寫入下一緩衝區
 ├── 2. 對積累數據進行均值/積分處理，消除高頻隨機白噪聲
 ├── 3. 讀取最新 BMP388 高度與速度
 ├── 4. 二階卡爾曼狀態更新：
 │      狀態量 X = [高度 h, 垂直速度 v]^T，狀態方程融合 BMI088 加速度計積分
 ├── 5. FSM 有限狀態機轉移判定 (動態頂點預測與安全高度強制開傘判定)
 └── 6. 打包數據並推入 OS 佇列 (Non-blocking Queue Send)
```

---

## 3. SD 卡非同步「雙緩衝」儲存機制 (Non-blocking Double-Buffering)

為防範 SD 卡在寫入 Sector 邊界或進行內部垃圾回收 (GC) 時產生的隨機**毫秒級阻塞 (Latency Spikes, 最長可達 80-150ms)** 餓死飛控任務，本系統實施了 **FreeRTOS 佇列 + RAM 雙緩衝區** 的非同步寫入架構。

### 3.1 系統架構圖 (Architecture flow)
```
[FlightControl_Task] (100Hz)
       |
       | (打包成 96-Byte 二進制日誌包)
       v
  [xDataLoggingQueue] (FreeRTOS Queue - 長度 200，可快取 2.0 秒數據)
       |
       | (佇列讀取 - 背景非同步)
       v
[DataLogging_Task] (優先級: Normal)
 ├── 1. 從佇列中提取二進制日誌包，將其格式化為 CSV 字串
 ├── 2. 寫入 RAM 當前快取緩衝區 Buffer_A
 ├── 3. 判斷 Buffer_A 是否已滿 (4096 位元組)？
 └── 4. 若滿：
         ├── 切換目前寫入指標至 Buffer_B (無縫持續收集後續數據)
         └── 觸發寫入執行緒：調用 FatFs f_write(Buffer_A) 批量寫入 SD 卡
         └── 調用 f_sync() 強制硬碟同步，保證斷電時已寫入資料 100% 安全
```

---

## 4. SD 卡儲存數據完整格式規範 (SD Card CSV Format Specification)

### 4.1 檔案命名與生命週期規則
* **命名規則**：系統初始化時，掛載 SD 卡並從 `FLIGHT_00.CSV` 開始進行遞增檢測，直到找到第一個不存在的序號，建立全新的日誌檔案，避免覆蓋歷史飛行資料。
* **文件安全性**：當狀態轉移至 `STATE_RECOVERY`（落地成功）時，`DataLogging_Task` 將執行 `f_close()` 並釋放檔案控制權，蜂鳴器長鳴提示「數據寫入安全，可拔除 SD 卡」。

### 4.2 CSV 檔案首部 Metadata 定義 (File Header)
CSV 日誌檔案前 10 行以 `#` 起始，以便於 Python (Pandas) 或 MATLAB 數據分析軟體自動跳過並直接讀取系統運行參數：

```csv
# RocketCup Avionics Flight Data Log
# Flight ID: FLIGHT_03.CSV
# OS Start Time: 2026-05-27 14:10:00
# System Config: magic=0x53595343, drogue_delay=4.00s, force_drogue=300.00m, main_target=150.00m, main_delay=3.50s
# Takeoff Config: takeoff_accel=3.00g, takeoff_height=10.00m, watchdog=2.00s
# Calib Offsets: AccelOffset_Z=0.012g, GyroOffset_X=0.045dps, GyroOffset_Y=-0.012dps, GyroOffset_Z=0.008dps
# Columns: Timestamp_ms,FSM_State,Kalman_H,Kalman_V,Baro_H,Baro_P,Acc_X_G,Acc_Y_G,Acc_Z_G,Gyro_X_dps,Gyro_Y_dps,Gyro_Z_dps,HG_Acc_X_G,HG_Acc_Y_G,HG_Acc_Z_G,Mag_X_mG,Mag_Y_mG,Mag_Z_mG,GPS_Lat,GPS_Lon,GPS_Alt,GPS_Sats,GPS_Fix,V_Bat,FIRE_Ch,Servo_Ang,CRC16
```

### 4.3 CSV 資料欄位對齊與精確格式 (Columns & Precision)

系統在寫入 SD 卡前，將數據轉化為工整的 ASCII CSV 格式，資料列無任何多餘空白，欄位精確定義如下：

| 欄位序號 | 欄位名稱 (Column Name) | 資料類型 (Type) | 格式範例 (Format) | 物理單位 (Unit) | 職責與資料來源描述 |
| :---: | :--- | :---: | :--- | :---: | :--- |
| **1** | `Timestamp_ms` | `uint32_t` | `102450` | ms | 自系統上電以來的累計毫秒數 |
| **2** | `FSM_State` | `uint8_t` | `4` | - | 有限狀態機當前狀態代碼 (1 ~ 10) |
| **3** | `Kalman_H` | `float` | `245.32` | m | 卡爾曼濾波平滑輸出之實時海拔高度 |
| **4** | `Kalman_V` | `float` | `45.12` | m/s | 卡爾曼濾波平滑輸出之垂直爬升/下降速度 |
| **5** | `Baro_H` | `float` | `244.89` | m | BMP388 氣壓計原始海拔高度 (200Hz 採樣) |
| **6** | `Baro_P` | `float` | `984.12` | hPa | BMP388 氣壓計原始氣壓讀值 |
| **7** | `Acc_X_G` | `float` | `-0.012` | g | BMI088 低G加速度計 X 軸原始值 (±24g 量程) |
| **8** | `Acc_Y_G` | `float` | `0.024` | g | BMI088 低G加速度計 Y 軸原始值 |
| **9** | `Acc_Z_G` | `float` | `1.004` | g | BMI088 低G加速度計 Z 軸原始值 |
| **10**| `Gyro_X_dps` | `float` | `0.12` | dps | BMI088 陀螺儀 X 軸角速度 (±2000dps 量程) |
| **11**| `Gyro_Y_dps` | `float` | `-0.45` | dps | BMI088 陀螺儀 Y 軸角速度 |
| **12**| `Gyro_Z_dps` | `float` | `0.08` | dps | BMI088 陀螺儀 Z 軸角速度 |
| **13**| `HG_Acc_X_G` | `float` | `0.45` | g | ADXL375 高G加速度計 X 軸原始值 (±200g 量程) |
| **14**| `HG_Acc_Y_G` | `float` | `-1.23` | g | ADXL375 高G加速度計 Y 軸原始值 |
| **15**| `HG_Acc_Z_G` | `float` | `9.81` | g | ADXL375 高G加速度計 Z 軸原始值 |
| **16**| `Mag_X_mG` | `float` | `245.2` | mG | MMC5983MA 地磁計 X 軸磁感應強度 (±8 Gauss) |
| **17**| `Mag_Y_mG` | `float` | `-12.5` | mG | MMC5983MA 地磁計 Y 軸磁感應強度 |
| **18**| `Mag_Z_mG` | `float` | `412.0` | mG | MMC5983MA 地磁計 Z 軸磁感應強度 |
| **19**| `GPS_Lat` | `double` | `25.0214567` | deg | NEO-M9N GPS 緯度數據 (高精度雙精度浮點) |
| **20**| `GPS_Lon` | `double` | `121.5428901`| deg | NEO-M9N GPS 經度數據 (高精度雙精度浮點) |
| **21**| `GPS_Alt` | `float` | `254.3` | m | NEO-M9N GPS 高度數據 |
| **22**| `GPS_Sats` | `uint8_t` | `14` | - | GPS 定位可見衛星顆數 |
| **23**| `GPS_Fix` | `uint8_t` | `3` | - | GPS 定位類型 (0:無定位, 2:2D定位, 3:3D定位) |
| **24**| `V_Bat` | `float` | `11.85` | V | 板載 ADC1_IN10 採樣分壓後之實時電池電壓 |
| **25**| `FIRE_Ch` | `uint8_t` | `0` | - | 引傘點火通道狀態 (0: 未導通, 1: PD13 MOSFET 導通) |
| **26**| `Servo_Ang` | `uint16_t` | `90` | deg | 主傘釋放舵機當前控制角度值 (0 ~ 180 度) |
| **27**| `CRC16` | `uint16_t` | `45231` | - | 該行字串之 CRC16 校驗值，確保日誌離線讀取完整性 |

---

## 5. 記憶體開銷與堆疊安全防護

為防止 FreeRTOS 堆疊溢出 (Stack Overflow)，對 5 大任務進行了嚴格的靜態記憶體配置規劃：

* **FlightControl_Task (512 Words / 2048 Bytes)**:
  * *堆疊監控*：僅使用輕量級局部變數。卡爾曼濾波器與狀態暫存器皆為 `static` 全域分配，防止因深層計算導致堆疊崩潰。
* **DataLogging_Task (512 Words / 2048 Bytes + 8KB Heap)**:
  * *記憶體優化*：`Buffer_A` 與 `Buffer_B` (共計 8KB) 必須使用 `static uint8_t` 進行全域編譯期靜態分配，絕不能在任務執行中動態調用 `malloc()`，保障堆疊線路絕對安全。
  * *溢出防範*：開啟 FreeRTOS 堆疊溢出檢測鉤子函數 `vApplicationStackOverflowHook`，一旦發生溢出，立即強行拉低 `PD13` (FIRE) 並拉響蜂鳴器，以防硬體誤點火。

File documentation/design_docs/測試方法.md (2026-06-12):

# RocketCom 航電系統測試環境與測試方法說明書

本文件詳細記錄了成大 ISP 航電組在 **STM32F407VGT6** 主控板上進行的軟韌體測試環境配置、硬體連接、各模組的測試方法以及驗證步驟，作為後續整合測試與發射準備的黃金參考標準。

---

## 📅 測試環境與基本規格

### 1. 硬體規格與核心晶片
* **核心主控**：STM32F407VGT6 (LQFP100)
* **板載感測器**：
  * 高-G 加速度計：`ADXL375` (±200g, SPI1)
  * 氣壓高度計：`BMP388` (厘米級相對高度, SPI1)
  * 標準姿態 IMU：`BMI088` (±24g 加速度 & ±2000°/s 角速度, SPI2)
* **板載儲存外設**：
  * SPI Flash：`W25Q128` (128M-bit / 16MB, SPI3)
  * SD 卡槽：MicroSD 卡槽 (SDIO 4-bit 模式)

### 2. 軟體與開發環境
* **開發工具**：STM32CubeIDE + STM32CubeMX
* **編譯工具鏈**：`arm-none-eabi-gcc` v16.1.0 / `arm-none-eabi-binutils` v2.46.0
* **作業系統**：FreeRTOS (CMSIS_V2)
* **文件系統**：FatFs 整合 (用於 SD 卡數據記錄)

---

## 🛠️ 一、 系統基礎測試環境與方法

### 1. LED 系統心跳指示燈測試
* **硬體引腳**：`PE2` (Net Label: `LED_SYS`)，控制邏輯為低電平點亮，高電平熄滅。
* **測試方法**：
  在 FreeRTOS 的預設任務 (Default Task) 循環中，使用定時器或 Tick 計數器進行分頻翻轉，形成 **1 Hz 的系統溫和心跳** (0.5 秒亮、0.5 秒暗)。
* **驗證指標**：
  * 板載 LED_SYS 呈現穩定的 1 Hz 呼吸閃爍。
  * 即使在高頻感測器採樣下，心跳燈亦無卡頓或頻率抖動，證明 RTOS 排程與空閒處理正常。

### 2. USART2 序列輸出與 printf 重定向
* **硬體引腳**：`PA2` (TX), `PA3` (RX)。
* **測試方法**：
  在 `main.c` 的 `USER CODE BEGIN 4` 區塊重定向 `_write` 函數，將標準 `printf` 輸出重定向至 `USART2` (HAL_UART_Transmit 阻塞傳輸)。
* **測試要點 (避免浮點解算開銷)**：
  在嵌入式系統中，為避免 `printf` 的 `%f` 嚴重消耗堆疊與 CPU 時間，所有感測器數據均在乘上固定倍率後轉為**整數**輸出：
  * 加速度數據：乘上 `1000` (單位：milli-g)
  * 高度與相對高度：乘上 `100` (單位：cm)
  * 溫度數據：乘上 `100` (單位：°C * 100)
* **驗證指標**：
  * 使用序列除錯助手 (如 `screen`, `PuTTY` 或 CubeIDE 內建 Terminal) 以波特率 **115200 bps** 連接，能流暢接收到實時遙測數據字串。

### 3. 獨立看門狗 (IWDG) 超時防禦測試
* **測試方法**：
  配置 IWDG 超時時間為約 2 秒。在 FreeRTOS 主任務無窮迴圈的頂端定期呼叫 `HAL_IWDG_Refresh(&hiwdg)`。
* **驗證方法**：
  * 在正常運作下，系統能持續輸出數據，無自動重啟現象。
  * 故意在程式碼中加入大於 2 秒的阻塞延遲（例如 `HAL_Delay(3000)`），驗證系統是否能成功被看門狗硬體重置 (Reset)，並在串口輸出重新啟動的日誌。

---

## 📡 二、 傳感器高頻中斷與雙緩衝測試方法

為了發揮感測器的最高物理採樣率，同時避免頻繁的上下文切換 (Context Switch) 拖垮 RTOS 任務，系統採用了**硬體定時器中斷 + Ping-Pong 雙緩衝區 (Double Buffer)** 機制。

### 1. ADXL375 高-G 加速度計高頻測試 (SPI1)
* **硬體引腳**：`PC4` (CS)，共用 SPI1。
* **測試方法**：
  1. 使用 **TIM3** 觸發 **3200 Hz** 硬體中斷。
  2. 在 TIM3 中斷服務程式中，直接透過 SPI1 讀取 ADXL375 的 3 軸加速度原始數據 (7 位元組，耗時約 5.6µs)，並寫入雙緩衝區 `ADXL_Sample_t g_adxl_batches[2][32]` (每 32 筆為一組 10ms 數據)。
  3. 當一組緩衝區寫滿時，中斷自動切換至另一組，並設置 `g_adxl_new_batch_ready = 1` 標誌。
  4. FreeRTOS 預設任務在 1ms 輪詢中偵測到該標誌時，一次性取出該批次 32 筆資料（降低任務開銷 96.8%）。
* **SPI1 總線互斥安全鎖**：
  由於 `ADXL375` (定時器中斷讀取) 與 `BMP388` (RTOS 任務層讀取) 共用 SPI1，為防止中斷搶佔導致 SPI 衝突，在任務層讀取 `BMP388` 前後，必須封裝中斷屏蔽鎖：
  ```c
  __HAL_TIM_DISABLE_IT(&htim3, TIM_IT_UPDATE);  // 暫停 TIM3 中斷
  BMP388_ReadData(&hspi1, &baro_data);          // 讀取 BMP388
  __HAL_TIM_ENABLE_IT(&htim3, TIM_IT_UPDATE);   // 恢復 TIM3 中斷
  ```
* **驗證指標**：
  * 實測採樣率精準鎖定在 **3200.0 Hz**。
  * 讀取 BMP388 時，兩者數據均正確無誤，無出現讀寫衝突或 SPI 卡死。

### 2. BMI088 標準姿態 IMU 高頻獨立測試 (SPI2)
* **硬體引腳**：`PB12` (ACCEL_CS)、`PB11` (GYRO_CS)、`PB13` (SCK)，專用 SPI2。
* **測試方法**：
  1. BMI088 加速度計物理極限為 1600 Hz，陀螺儀物理極限為 2000 Hz。
  2. 使用 **TIM6** 觸發 **1600 Hz** 中斷，在其中讀取加速度數據並寫入雙緩衝區 `g_bmi_acc_batches[2][16]`。
  3. 使用 **TIM7** 觸發 **2000 Hz** 中斷，在其中讀取陀螺儀數據並寫入雙緩衝區 `g_bmi_gyro_batches[2][20]`。
  4. 由於 SPI2 專屬於 BMI088，無任何任務層讀寫，因此本架構為 **Zero-Lock 免鎖設計**，兩個定時器中斷可安全併行，無需任何中斷屏蔽鎖。
* **驗證指標**：
  * 加速度計採樣率精準達到 **1600.0 Hz**。
  * 陀螺儀採樣率精準達到 **2000.0 Hz**。
  * 即使長時間在高頻中斷下運作，系統依然維持穩定。

### 3. BMP388 氣壓高度計測試 (SPI1)
* **硬體引腳**：`PA4` (CS)，共用 SPI1。
* **測試方法**：
  1. 引入 Bosch 官方 `BMP3 Sensor API` (v2) 以確保補償多項式解算精度。
  2. 為了在 **200 Hz ODR** 週期 (5ms) 下穩定工作，配置為 **1x 氣壓過採樣** 與 **1x 溫度過採樣**，確保轉換時間 $T_{conv} \approx 4.94\text{ ms} < 5\text{ ms}$。
  3. 在 FreeRTOS 預設任務中，每 5ms (200 Hz) 呼叫一次 API 讀取數據。
* **驗證指標**：
  * 高度計輸出氣壓與厘米級相對高度，對手部抬起、吹氣等物理動作有即時靈敏的高度變化反應。

---

## 💾 三、 儲存外設測試環境與方法

### 1. W25Q128 SPI Flash 測試 (SPI3)
* **硬體引腳**：`PA15` (CS)、`PB3` (SCK)、`PB4` (MISO)、`PB5` (MOSI)。
* **測試方法**：
  1. 主控板透過獨立的 **SPI3** 與 W25Q128 連接。
  2. **啟動自檢**：讀取 W25Q128 的 JEDEC ID。
  3. **讀寫校驗**：
     * 對 Sector 0 進行擦除 (Erase) 操作。
     * 向頁面 (Page) 寫入一段長度為 61 標記的校驗測試字串。
     * 重新讀取寫入的數據，進行 100% 逐字節校驗比對。
* **驗證指標**：
  * JEDEC ID 讀取必須為 **`0xEF4018`**。
  * 寫入的測試數據與讀回的數據完全一致，自檢測試輸出 `[Flash] ✅ Write and Read verification 100% SUCCESS!`。

### 2. SD 卡高速數據日誌測試 (SDIO)
* **硬體引腳**：
  * `PC8` ~ `PC11` (D0 ~ D3), `PC12` (CLK), `PD2` (CMD)。
  * **`PD3`** (Net Label: `SDIO_DET_Pin`) 插入檢測引腳。
* **測試方法**：
  1. **插卡防空保護**：
     * 將 `SDIO_DET_Pin` (PD3) 配置為內部強上拉 **`GPIO_PULLUP`**，防止引腳浮空導致假性插卡檢測。
     * 程式啟動後先進行非阻塞的 FatFs 磁碟掛載 (`f_mount(&SDFatFS, SDPath, 0)`)。
     * 讀取 PD3 的狀態，僅當其為低電平 (GPIO_PIN_RESET，表示有卡插入) 時，才執行建立 CSV 檔案 (`f_open`) 與寫入。若為高電平 (無卡)，則優雅跳過，避免總線讀寫卡死。
  2. **10 秒 100 Hz CSV 高頻寫入**：
     * 偵測到插卡後，在預設任務循環中，每 10ms (100 Hz) 將當前 Tick、BMI088、ADXL375、BMP388 的實時感測器數據打包成 CSV 字串寫入 `HIL_10S.CSV`。
     * 寫入持續整整 10 秒 (10000ms)。
  3. **安全卸載**：
     * 10 秒結束後，立即呼叫 `f_close(&SDFile)` 關閉檔案，並執行 `f_mount(NULL, SDPath, 1)` 強制物理卸載，確保所有緩衝區數據實體寫入磁碟，防止斷電丟失。
* **驗證指標**：
  * **無卡測試**：在未插卡時，系統能流暢啟動，串口遙測輸出無任何卡頓或延遲。
  * **有卡測試**：插入 MicroSD 卡上電，串口輸出 `[SD] ✅ 檢測到 SD 卡已插入！正在建立 HIL_10S.CSV 檔案...`。
  * 10 秒後串口輸出 `[SD] 🎉 10 秒數據寫入結束！檔案已安全關閉並儲存 (HIL_10S.CSV)。`。
  * 將 MicroSD 卡放入電腦中，讀取 `HIL_10S.CSV`，確認 CSV 格式正確，含有完整 1000 筆感測器高頻數據且無資料破損。

---

## 🏃 四、 測試執行步驟與操作指南

### 步驟 1：硬體準備與接線
1. 將測試用 **STM32F407VGT6** 核心主控板放置於防靜電墊上。
2. 插入一張 FAT32 格式的 MicroSD 卡至板載卡槽中（若要測試防空保護，可先不插）。
3. 使用 USB-TTL 轉接線，將電腦的 RX/TX 分別連接至主控板的 **PA2** (TX) / **PA3** (RX)，並共用 GND。
4. 電腦開啟序列除錯工具，連接對應的 COM Port，參數設定為 `115200 bps, 8-N-1`。
5. 將 ST-LINK 燒錄器連接至板載 SWD 接口。

### 步驟 2：編譯與燒錄
1. 在專案根目錄下，開啟終端機並確認 GCC 工具鏈已在 PATH 中。
2. 執行編譯命令：
   ```bash
   make -j4
   ```
3. 編譯完成後，使用 ST-LINK 程式 (或 STM32CubeProgrammer) 將 `Main_AV_F407/Debug/bigav_407.bin` (或 hex) 燒錄至晶片中。

### 步驟 3：運行與串口觀測
1. 按下板載的 Reset 按鈕重置晶片。
2. 觀察串口輸出，預期應依序顯示以下自檢與日誌：
   * 系統啟動，LED 開始 1 Hz 慢閃。
   * **Flash 自檢**：顯示 JEDEC ID 為 `0xEF4018` 並通過讀寫驗證。
   * **SD 卡檢測**：顯示檢測到插卡，建立 `HIL_10S.CSV`，並開始 100 Hz 高頻寫入。
   * **數據日誌**：10 秒期間，串口會定頻輸出當前感測器（BMI088、ADXL375、BMP388）的遙測數據（乘上倍率後的整數值）。
   * **卸載通知**：10 秒後，輸出日誌結束，SD 卡安全關閉並卸載。

---
*文件編修者：成大 ISP 航電組開發團隊*
*更新日期：2026-05-27*

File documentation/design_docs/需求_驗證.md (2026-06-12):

# 航電系統需求與驗證追蹤表 (Requirements & Verification Matrix)

本文件用以追蹤航電系統的核心需求，並記錄各需求的驗證時間、驗證方法與當前狀態。

---

## 一、 系統需求與設計矩陣

| 需求編號 | 需求階層 | 需求內容 | 需求來源 | 需求類型 | 需要此需求的原因 | 驗證方法 | 當前狀態 |
| :--- | :--- | :--- | :--- | :--- | :--- | :--- | :---: |
| **REQ-SYS-01** | 次系統需求 | 航電系統應具備電壓監控功能 | 系統工程 | 功能需求 | 需要監控電池電壓，以確保系統能正常運作，並避免電池過放 | 實體 ADC 電壓採樣與遙測顯示 (展示) | **已驗證** |
| **REQ-SYS-02** | 次系統`需求 | 航電系統須具有實體總開關 | 航電安全 | 功能需求 | 安全切斷電源，防止地面待機放電與意外點火 | 實體開關斷路測試 (展示) | **已驗證** |
| **REQ-SYS-03** | 次系統需求 | 航電系統應具有防水功能 | 環境適應 | 非功能需求 | 防範發射場下雨、高濕度環境，或火箭落水時保護數據 | 艙體密封性與防潑水測試 (分析) | **待驗證** |
| **REQ-SYS-04** | 系統需求 | 航電系統須能承受飛行過程的震動/衝擊 | 結構載荷 | 非功能需求 | 承受發動機燃燒高頻震動與開傘瞬間的巨大拉力衝擊 | 振動台模擬與撞擊測試 (測試) | **待驗證** |
| **REQ-SYS-05** | 系統需求 | 航電系統須具備導航定位相關硬體 | 導航回收 | 功能需求 | 提供實時軌跡追蹤，並在落地後發射訊號以利尋標回收 | GPS 模組收星與 LoRa/蜂鳴器測試 (測試) | **已驗證** |
| **REQ-SYS-06** | 次系統需求 | 航電系統應具備空中斷電熱啟動恢復功能 | 容錯安全 | 功能需求 | 防止飛行中瞬間因高G力震動斷電或軟體看門狗重啟，導致系統失效與開傘失敗 | 硬體模擬空中瞬間斷電並重啟驗證 (測試) | **尚未驗證** |

---

## 二、 已進行的驗證記錄歷程 (Verification Records)

以下記錄專案開發過程中，各項需求與功能的實體/模擬驗證歷程：

### 1. [已驗證] 電子羅盤實體線路接反與 GPS 鮑率錯誤戰術救援
* **驗證時間**：2026-06-03
* **對應需求**：REQ-SYS-05 (導航定位相關硬體)
* **驗證方式**：
  * **硬體現況**：發現 PCB 走線中 I2C1 SCL 與 SDA 接腳與晶片硬體定義相反，且 GPS 預設為 38400 bps 與原代碼 115200 bps 不符。
  * **驗證手段**：實作軟體模擬 I2C 驅動（SCL=PB7, SDA=PB8，採開漏輸出），並將 GPS 串口 (USART6) 鲍率修正為 38400 bps。透過 USART2 串口遙測觀測數據。
  * **驗證結果**：地磁計 MMC5983MA 成功讀取 (`ok=921, err=0`)，GPS NMEA 數據流零校驗錯誤流暢解析 (`ok=60, err=0`)，採樣率監測器顯示正常。

### 2. [已驗證] SD 卡高頻數據全程日誌寫入與無卡防卡死優化
* **驗證時間**：2026-06-01
* **對應需求**：REQ-SYS-05 (導航定位與數據保存)
* **驗證方式**：
  * **驗證手段**：模擬飛行過程進行 SDIO 寫入。配置 `SDIO_DET_Pin` 為上拉電阻，以防引腳浮空卡死；並在 `StartDefaultTask` 內實作 FSM 狀態驅動：升空至落地前以 100Hz 記錄，落地後降為 10Hz，並於落地超過 30 分鐘或按壓 `USER_BT1` 時安全關閉檔案。
  * **驗證結果**：SD 卡於無卡狀態下能優雅跳過，有卡時能自動以 `HIL_001.CSV`～`HIL_999.CSV` 遞增建檔，高頻連續寫入無卡死，每秒 `f_sync` 寫入成功。

### 3. [已驗證] Buzzer 開機提示音與 32-bit ARR 溢出修正
* **驗證時間**：2026-06-01
* **對應需求**：系統狀態反饋
* **驗證方式**：
  * **驗證手段**：配置 TIM2 CH1 PWM，控制蜂鳴器在初始化結束後發出 2kHz -> 4kHz 的兩聲漸高音。針對 ARR 動態縮小時若 CNT 已大於新 ARR 會導致等候 4295 秒的 Bug，改用手動觸發 `EGR = TIM_EGR_UG` 即時歸零 CNT。
  * **驗證結果**：蜂鳴器發聲宏亮，且連續多次重啟皆能穩定發出開機兩聲提示音。

### 4. [已驗證] Flash 環形日誌緩衝區 (Ring Buffer) HIL 驗證
* **驗證時間**：2026-05-27
* **對應需求**：REQ-SYS-05 (飛行數據保存)
* **驗證方式**：
  * **驗證手段**：透過 SPI3 匯流排對 W25Q128 進行 30 秒硬體迴路測試 (HIL)。以 20Hz 寫入 52-byte packed 封包，並在寫入前執行二分搜尋（Binary Search）快速恢復寫入頭，同時進行 10 個 Sector (40KB) 預擦除。
  * **驗證結果**：30秒內寫入 461 筆封包，透過串口 Dump 讀回，所有 magic bytes (`0xAA 0x55`) 與 CRC-16/CCITT 校验 100% 通過。

### 5. [已驗證] 高頻定時器中斷與雙緩衝 (Ping-Pong) 感測器採樣
* **驗證時間**：2026-05-27
* **對應需求**：REQ-SYS-05 (高頻運動數據獲取)
* **驗證方式**：
  * **驗證手段**：設定 TIM6 (1.6 kHz 中斷讀 BMI088 加速度計)、TIM7 (2.0 kHz 中斷讀 BMI088 陀螺儀)、TIM3 (3.2 kHz 中斷讀 ADXL375 高 G 加速度計)。中斷內資料打包存入雙緩衝區，任務層每 10ms 讀取最新批次。
  * **驗證結果**：實測物理採樣頻率精準達到設計極限：BMI088 加速度 1600.0Hz、陀螺儀 2000.0Hz、ADXL375 3200.0Hz，且無總線衝突，CPU 上下文切換開銷降低 96.8%。

### 6. [已驗證] 獨立看門狗 (IWDG) 快速復位保護
* **驗證時間**：2026-05-27
* **對應需求**：系統容錯安全
* **驗證方式**：
  * **驗證手段**：配置 IWDG 使用 LSI 32kHz 振盪器，除以 16 分頻，載入值 4095，將超時設為 2.05 秒。在主任務主迴圈中每毫秒進行一次餵狗。
  * **驗證結果**：當任務正常運行時系統無誤復位；當人工在代碼中加入死迴圈阻塞時，系統在精準的 2.05 秒重啟。

---

## 三、 當前待驗證與尚未驗證項目 (Pending Verifications)

1. **空中斷電熱啟動恢復功能 (REQ-SYS-06)**
   * **狀態**：**尚未驗證** (代碼已完成，等待硬體 HIL 測試)。
   * **驗證方式與步驟**：
     * **[1] 斷電模擬**：在發射台 PAD 狀態完成 3 秒自檢校準（此時已將 biases 寫入 Sector 0）。模擬點火升空進入 `STATE_BOOST` 或 `STATE_COAST`，並在此期間手動切斷系統電源 2~3 秒後重新接通。
     * **[2] 狀態恢復觀測**：重新上電後，觀察 UART 終端機與遙測數據是否成功跳過 3 秒自檢校準，加載 `reboot_count` 並遞增，繼承斷電前的 FSM 狀態。
     * **[3] 數據平滑性**：驗證是否正確讀取 Sector 0 的基準高度與 biases，並利用 Ring Buffer 最後兩筆數據差分估算 Z 速度，將高度、垂直速度與四元數姿態平滑注入 EKF，無階躍發散。

2. **20s 內手動 EKF 重新校準與高度歸零 (USER_BT1 短按與 3kHz 雙短鳴)**
   * **狀態**：**尚未驗證** (代碼已完成，等待上板測試)。
   * **驗證方式與步驟**：
     * **[1] 觸發測試**：上電開機 20 秒內，傾斜航電板使姿態估計偏離。按下 `USER_BT1` 鍵。
     * **[2] 確認反饋**：確認蜂鳴器響起非阻塞的 3kHz 雙短鳴（確認音），且遙測終端輸出 `[EKF] Static calibration reset triggered!`。
     * **[3] 校準重建**：確認系統重新執行 3000 筆感測器數據的靜態偏差估計，校準完成後自動調用 `EKF_SaveCalibrationToFlash` 將最新的零偏寫入 Flash Sector 0。

3. **開機手動清除 Flash 狀態 (USER_BT2 擦除 Ring Buffer 標記區)**
   * **狀態**：**尚未驗證** (代碼已完成，等待上板測試)。
   * **驗證方式與步驟**：
     * **[1] 擦除測試**：上電開機時按住 `USER_BT2` 鍵。
     * **[2] 確認反饋**：確認蜂鳴器響起 300ms 的持續蜂鳴聲，且終端輸出 `[SYS] Flash Ring Buffer 標記已成功擦除！`。
     * **[3] 預期結果**：系統應完全重置 Ring Buffer 首尾 Sector 標記。此時即使前一次飛行中斷，開機重啟亦判定為正常地面起飛，進入 `STATE_PAD` 模式。

4. **80-Byte telemetry 封包與落海 1Hz 記錄速率變更**
   * **狀態**：**尚未驗證** (代碼已完成，等待上板測試)。
   * **驗證方式與步驟**：
     * **[1] telemetry 格式對齊**：觀察 Ring Buffer 寫入的封包格式，大小已調整為 80-byte。落地後導出 Flash 與 SD 卡的 CSV 比對，確認 EKF 四元數（q0, q1, q2, q3）、高度、速度、GPS 等欄位 100% 一致。
     * **[2] 降頻紀錄**：當飛行狀態機進入 `STATE_LANDED`（安全著陸）後，確認 Flash 寫入頻率成功由 50Hz 降為 1Hz，且無 IWDG 餵狗溢出或 FSM 卡死。

5. **著陸一次性寫入系統旗標與任務總結 (Sector 0/1 防飛行擦除安全鎖)**
   * **狀態**：**尚未驗證** (代碼已完成，等待上板測試)。
   * **驗證方式與步驟**：
     * **[1] 飛行安全鎖驗證**：在起飛至下降的整個飛行過程中，監控 W25Q128 的 SPI3 總線，確認除 Page Program 外無任何 Sector Erase 指令發送，防止 CPU 卡死阻塞。
     * **[2] 著陸寫入驗證**：進入 `STATE_LANDED` 瞬間（g_touchdown_tick 首次記錄），觀察 Sector 0 與 Sector 1 被擦除寫入。讀出 static 區，確認最高高度、最大速度、過載極值、狀態時間戳、發射點/落地點 GPS 與 reboot 次數均成功寫入。

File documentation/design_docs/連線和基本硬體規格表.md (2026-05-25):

# 航電系統連線與基本硬體規格表 (Avionics Golden Reference)

> [!NOTE]
> 本文件為 **RocketCom 航電系統主控板** 的官方硬體規格與引腳分配黃金參考手冊（Golden Reference）。
> 旨在提供後續 AI 程式開發代理人 (AI Agent) 與韌體工程師在撰寫 STM32 C/C++ 韌體（HAL/LL 庫）或 Arduino 測試程式時，能擁有 100% 精確的硬體對照指引，免去反覆查閱 KiCad 原理圖與 PCB 佈線檔的繁瑣步驟。

---

## 1. 系統核心架構簡介

本系統採用 **四層堆疊板 (4-Layer Stacked Design)** 架構，主要包含以下層次：
1. **頂層介面與感測器層 (Top Layer)**：搭載 GPS 定位模組與地磁計（磁力計）。
2. **主控 MCU 層 (Second Layer MCU)**：系統核心。主控晶片因缺料替代為 **STM32F407VGT6**（與原設計 STM32F405VGT6 之 Pinout 完全一致且相容），板載核心 IMU、高G值加速度計、氣壓計（因缺料改用 **BMP388**，與原設計 BMP390 之 Pinout 完全一致且相容）、高容量 Flash 快閃記憶體與 MicroSD 卡槽。
3. **無線通訊層 (LoRa Layer)**：集成 433MHz（UART 介面）與 920MHz（SPI 介面）雙頻段 LoRa 無線遙測模組。
4. **電源管理層 (Power Layer)**：高效率雙路 DC-DC 降壓、雙電源切換與電池電壓監測系統。

---

## 2. STM32F407VGT6 (LQFP100) 完整引腳分配表 (相容 STM32F405VGT6)

以下為透過電路板佈線實測 100% 導出的物理引腳 (Pad) 與全域網路標籤 (Net Label) 的對照表：

| 引腳 (Pad) | GPIO 名稱 | 連接網路標籤 (Net) | 週邊設備 / 功能描述 | 電源軌 |
| :---: | :---: | :--- | :--- | :---: |
| **1** | **PE2** | `LED_SYS` | 系統運行指示 LED 燈（低電平/高電平控制） | 3.3V |
| **2** | **PE3** | `LED_State1` | 狀態指示 LED 燈 1 | 3.3V |
| **3** | **PE4** | `LED_State2` | 狀態指示 LED 燈 2 | 3.3V |
| **4** | **PE5** | `N/C` | 未連接 (Unconnected) | - |
| **5** | **PE6** | `N/C` | 未連接 (Unconnected) | - |
| **6** | **VBAT** | `+3.3V` | 備用電池電源輸入 | 3.3V |
| **7** | **PC13** | `N/C` | 未連接 (Unconnected) | - |
| **8** | **PC14** | `N/C` | 未連接 (Unconnected) | - |
| **9** | **PC15** | `N/C` | 未連接 (Unconnected) | - |
| **10** | **VSS** | `GND` | 系統地 | 0V |
| **11** | **VDD** | `+3.3V` | 系統數位電源 | 3.3V |
| **12** | **PH0** | `HSE_IN` | 外部高速晶振輸入 (16.0000 MHz) | 3.3V |
| **13** | **PH1** | `HSE_OUT` | 外部高速晶振輸出 | 3.3V |
| **14** | **NRST** | `RESET` | 系統硬體重置腳 | 3.3V |
| **15** | **PC0** | `Battery_Sensing` | 電池電壓類比量測腳 (**ADC1_IN10**) | 類比 |
| **16** | **PC1** | `SUP_STAT` | 電源切換狀態指示（低電平表示 USB 供電中） | 3.3V |
| **17** | **PC2** | `N/C` | 未連接 (Unconnected) | - |
| **18** | **PC3** | `USER_BT2` | 使用者按鍵 2 輸入（帶外部上拉） | 3.3V |
| **19** | **VSSA** | `GND` | 類比地 | 0V |
| **20** | **VREF-** | `GND` | 類比參考地 | 0V |
| **21** | **VREF+** | `VREF` | 類比參考正電壓 (接 +3.3V 濾波) | 3.3V |
| **22** | **VDDA** | `+3.3V` | 系統類比電源 | 3.3V |
| **23** | **PA0** | `Buzzer` | 有源蜂鳴器控制引腳（高電平驅動） | 3.3V |
| **24** | **PA1** | `USER_BT1` | 使用者按鍵 1 輸入（帶外部上拉） | 3.3V |
| **25** | **PA2** | `USART2_TX` | 外部 UART2 傳送 (擴充除錯/串列埠) | 3.3V |
| **26** | **PA3** | `USART2_RX` | 外部 UART2 接收 | 3.3V |
| **27** | **VSS** | `GND` | 系統地 | 0V |
| **28** | **VDD** | `+3.3V` | 系統數位電源 | 3.3V |
| **29** | **PA4** | `CSB_Baro` | BMP388 氣壓計 SPI 片選腳 (**CS**) | 3.3V |
| **30** | **PA5** | `SPI1_SCK` | SPI1 時鐘線 (共用：氣壓計、高G加速度計、Flash) | 3.3V |
| **31** | **PA6** | `SPI1_MISO` | SPI1 主入從出線 | 3.3V |
| **32** | **PA7** | `SPI1_MOSI` | SPI1 主出從入線 | 3.3V |
| **33** | **PC4** | `CSB_HIGH_G` | ADXL375 高G加速度計 SPI 片選腳 (**CS**) | 3.3V |
| **34** | **PC5** | `INT_High_G2` | ADXL375 高G加速度計中斷輸出 2 | 3.3V |
| **35** | **PB0** | `INT_High_G1` | ADXL375 高G加速度計中斷輸出 1 | 3.3V |
| **36** | **PB1** | `INT_Baro` | BMP388 氣壓計中斷輸出腳 | 3.3V |
| **37** | **PB2** | `BOOT1` | 系統啟動模式設定腳 1 | 3.3V |
| **38** | **PE7** | `INT_Accel1` | BMI088 IMU 加速度計中斷輸出 1 | 3.3V |
| **39** | **PE8** | `INT_Accel2` | BMI088 IMU 加速度計中斷輸出 2 | 3.3V |
| **40** | **PE9** | `INT_Gyro1` | BMI088 IMU 陀螺儀中斷輸出 1 | 3.3V |
| **41** | **PE10** | `INT_Gyro2` | BMI088 IMU 陀螺儀中斷輸出 2 | 3.3V |
| **42** | **PE11** | `LORA433_BUSY` | E22-400T30S 433MHz LoRa 狀態忙碌指示腳 (AUX) | 3.3V |
| **43** | **PE12** | `INT_Magn` | MMC5983MA 地磁計中斷輸出腳 | 3.3V |
| **44** | **PE13** | `N/C` | 未連接 (Unconnected) | - |
| **45** | **PE14** | `N/C` | 未連接 (Unconnected) | - |
| **46** | **PE15** | `N/C` | 未連接 (Unconnected) | - |
| **47** | **PB10** | `N/C` | 未連接 (Unconnected) | - |
| **48** | **PB11** | `CSB_Gyro` | BMI088 IMU 陀螺儀 SPI 片選腳 (**CS**) | 3.3V |
| **49** | **VCAP_1** | `VCAP_1` | 內部電壓調節器濾波電容連接端 1 | - |
| **50** | **VDD** | `+3.3V` | 系統數位電源 | 3.3V |
| **51** | **PB12** | `CSB_Accel` | BMI088 IMU 加速度計 SPI 片選腳 (**CS**) | 3.3V |
| **52** | **PB13** | `SPI2_SCK` | SPI2 時鐘線 (專用於 BMI088 IMU 晶片) | 3.3V |
| **53** | **PB14** | `SPI2_MISO` | SPI2 主入從出線 | 3.3V |
| **54** | **PB15** | `SPI2_MOSI` | SPI2 主出從入線 | 3.3V |
| **55** | **PD8** | `N/C` | 未連接 (Unconnected) | - |
| **56** | **PD9** | `UART3_RX` | E22-400T30S 433MHz LoRa 遙測接收端 | 3.3V |
| **57** | **PD10** | `LORA433_M1` | E22-400T30S 433MHz LoRa 模式控制腳 M1 | 3.3V |
| **58** | **PD11** | `LORA433_M0` | E22-400T30S 433MHz LoRa 模式控制腳 M0 | 3.3V |
| **59** | **PD12** | `LORA433_RST` | E22-400T30S 433MHz LoRa 模組硬體重置腳 | 3.3V |
| **60** | **PD13** | `FIRE` | 點火/觸發開關控制引腳（MOSFET 高電平驅動） | 3.3V |
| **61** | **PD14** | `N/C` | 未連接（註：主控板上此腳未拉出，TIM4_CH3 暫留） | - |
| **62** | **PD15** | `N/C` | 未連接 (Unconnected) | - |
| **63** | **PC6** | `USART6_TX` | NEO-M9N GPS 模組序列接收端 (對應 GPS Rx) | 3.3V |
| **64** | **PC7** | `UART6_RX` | NEO-M9N GPS 模組序列傳送端 (對應 GPS Tx) | 3.3V |
| **65** | **PC8** | `SDIO_D0` | MicroSD 卡 SDIO 資料線 0 | 3.3V |
| **66** | **PC9** | `SDIO_D1` | MicroSD 卡 SDIO 資料線 1 | 3.3V |
| **67** | **PA8** | `RST_GPS` | NEO-M9N GPS 模組硬體重置腳（低電平有效） | 3.3V |
| **68** | **PA9** | `USB_VBUS` | USB 連接埠 VBUS 電壓偵測腳 | 5V 容忍 |
| **69** | **PA10** | `N/C` | 未連接 (Unconnected) | - |
| **70** | **PA11** | `USB_D-` | On-Chip USB-OTG FS 資料負線 | 3.3V |
| **71** | **PA12** | `USB_D+` | On-Chip USB-OTG FS 資料正線 | 3.3V |
| **72** | **PA13** | `SWDIO` | SWD 偵錯埠資料線 | 3.3V |
| **73** | **VCAP_2** | `VCAP_2` | 內部電壓調節器濾波電容連接端 2 | - |
| **74** | **VSS** | `GND` | 系統地 | 0V |
| **75** | **VDD** | `+3.3V` | 系統數位電源 | 3.3V |
| **76** | **PA14** | `SWCLK` | SWD 偵錯埠時鐘線 | 3.3V |
| **77** | **PA15** | `CSB_Flash` | W25Q128 快閃記憶體 SPI 片選腳 (**CS**) | 3.3V |
| **78** | **PC10** | `SDIO_D2` | MicroSD 卡 SDIO 資料線 2 | 3.3V |
| **79** | **PC11** | `SDIO_D3` | MicroSD 卡 SDIO 資料線 3 | 3.3V |
| **80** | **PC12** | `SDIO_CK` | MicroSD 卡 SDIO 時鐘線 | 3.3V |
| **81** | **PD0** | `N/C` | 未連接 (Unconnected) | - |
| **82** | **PD1** | `N/C` | 未連接 (Unconnected) | - |
| **83** | **PD2** | `SDIO_CMD` | MicroSD 卡 SDIO 命令線 | 3.3V |
| **84** | **PD3** | `SDIO_DET` | MicroSD 卡槽卡片插入偵測腳 (GPIO 中斷) | 3.3V |
| **85** | **PD4** | `LORA920_INT` | E80-900M23S 920MHz LoRa 中斷腳 (**EXTI4**) | 3.3V |
| **86** | **PD5** | `LORA920_RST` | E80-900M23S 920MHz LoRa 重置腳 | 3.3V |
| **87** | **PD6** | `LORA920_BUSY` | E80-900M23S 920MHz LoRa 狀態忙碌指示腳 | 3.3V |
| **88** | **PD7** | `CSB_LORA920` | E80-900M23S 920MHz LoRa SPI 片選腳 (**CS**) | 3.3V |
| **89** | **PB3** | `SPI3_SCK` | SPI3 時鐘線 (專用於 920MHz LoRa 遙測模組) | 3.3V |
| **90** | **PB4** | `SPI3_MISO` | SPI3 主入從出線 | 3.3V |
| **91** | **PB5** | `SPI3_MOSI` | SPI3 主出從入線 | 3.3V |
| **92** | **PB6** | `N/C` | 未連接 (Unconnected) | - |
| **93** | **PB7** | `I2C1_SCL` | **特殊注意**：硬體實體接線至 I2C1_SCL | 3.3V |
| **94** | **BOOT0** | `BOOT0` | 系統啟動模式設定腳 0 (帶 10k 下拉電阻) | 0V |
| **95** | **PB8** | `I2C1_SDA` | **特殊注意**：硬體實體接線至 I2C1_SDA | 3.3V |
| **96** | **PB9** | `N/C` | 未連接 (Unconnected) | - |
| **97** | **PE0** | `N/C` | 未連接 (Unconnected) | - |
| **98** | **PE1** | `N/C` | 未連接 (Unconnected) | - |
| **99** | **VSS** | `GND` | 系統地 | 0V |
| **100** | **VDD** | `+3.3V` | 系統數位電源 | 3.3V |

> [!WARNING]
> ### 🚨 I2C1 引腳配置重要警告
> 在標準 STM32 預設配置中，`PB6` 通常為 I2C1_SCL，`PB7` 為 I2C1_SDA。
> **但在本航電主控板的實體硬體設計中：**
> * **I2C1_SCL** 連接至 **PB7 (Pad 93)**
> * **I2C1_SDA** 連接至 **PB8 (Pad 95)**
> 在初始化 STM32 HAL/LL 庫或進行 CubeMX/CubeIDE 設定時，**必須手動重定義 Pin 腳映射為 `SCL = PB7`, `SDA = PB8`**，否則地磁計 (MMC5983MA) 將完全無法進行通訊！

---

## 3. 通訊匯流排週邊分配表 (Bus Peripherals)

為維持高可靠性，硬體對通訊匯流排進行了隔離設計，避免單一感測器異常導致全匯流排崩潰：

### 3.1 SPI1 匯流排 (高速，主要感測器與資料快閃記憶體)
* **MCU 引腳**：`SCK = PA5` / `MISO = PA6` / `MOSI = PA7`
* **掛載設備**：
  1. **BMP388 氣壓計**：片選腳 = `PA4 (CSB_Baro)`，最大支援 10MHz SPI 速率 (因晶片缺料替代原設計之 BMP390，引腳完全相容)。
  2. **ADXL375 高G加速度計**：片選腳 = `PC4 (CSB_HIGH_G)`，最大支援 5MHz SPI 速率。
  3. **W25Q128 快閃記憶體**：片選腳 = `PA15 (CSB_Flash)`，最大支援 104MHz SPI 速率。

### 3.2 SPI2 匯流排 (專用於核心姿勢 IMU)
* **MCU 引腳**：`SCK = PB13` / `MISO = PB14` / `MOSI = PB15`
* **掛載設備**：
  1. **BMI088 核心 IMU (加速度計)**：片選腳 = `PB12 (CSB_Accel)`，最大支援 10MHz SPI 速率。
  2. **BMI088 核心 IMU (陀螺儀)**：片選腳 = `PB11 (CSB_Gyro)`，最大支援 10MHz SPI 速率。

### 3.3 SPI3 匯流排 (專用於遠程遙測)
* **MCU 引腳**：`SCK = PB3` / `MISO = PB4` / `MOSI = PB5`
* **掛載設備**：
  1. **E80-900M23S (920MHz LoRa 遙測模組)**：片選腳 = `PD7 (CSB_LORA920)`，硬體重置 = `PD5`，中斷腳 = `PD4`，忙碌腳 = `PD6`。

### 3.4 I2C1 匯流排 (磁力計)
* **MCU 引腳**：`SCL = PB7` / `SDA = PB8` (具外部 2.7k 上拉電阻)
* **掛載設備**：
  1. **MMC5983MA 高精度三軸地磁計**：中斷腳 = `PE12`。

### 3.5 UART 序列通訊匯流排
* **UART3** (`TX = PB10` / `RX = PD9`)：
  * **掛載設備**：**E22-400T30S (433MHz LoRa 模組)**。
  * **控制引腳**：重置 = `PD12`，模式 M0 = `PD11`，模式 M1 = `PD10`，忙碌 AUX = `PE11`。
* **UART6** (`TX = PC6` / `RX = PC7`)：
  * **掛載設備**：**NEO-M9N-00B (GPS 定位模組)**。
  * **控制引腳**：重置 = `PA8`。
* **USART2** (`TX = PA2` / `RX = PA3`)：
  * **用途**：預留外部排針除錯/地面有線通訊埠。

### 3.6 SDIO 匯流排 (大容量數據記錄)
* **MCU 引腳**：`D0=PC8`, `D1=PC9`, `D2=PC10`, `D3=PC11`, `CLK=PC12`, `CMD=PD2`
* **偵測腳**：`SDIO_DET = PD3`（高電平/低電平判斷是否有卡片插入，支援中斷觸發）

---

## 4. 關鍵感測器與晶片規格

為撰寫驅動程式，以下彙整硬體上各晶片的核心規格與介面細節：

### 4.1 BMI088 六軸慣性測量單元 (IMU)
* **功能**：負責火箭飛行姿態、角速度及標準加速度量測（飛行姿態控制核心）。
* **SPI 通訊模式**：SPI Mode 3 (CPOL=1, CPHA=1) 或 Mode 0 (CPOL=0, CPHA=0)。
* **暫存器讀寫規則**：讀取暫存器時，SPI 位元組需包含讀寫控制位元（Bit 7 = 1 表示讀取，0 表示寫入）。加速度計在傳送完暫存器地址後，需要多一個 Dummy Byte 才能讀出有效數據。
* **量程設定建議**：
  * **加速度計**：建議設為 **±24g**（最高支援），頻寬建議設為 280Hz。
  * **陀螺儀**：建議設為 **±2000 °/s**，頻寬建議設為 532Hz。

### 4.2 BMP388 高精度氣壓計 (因缺料替代原設計之 BMP390，Pinout 完全一致)
* **功能**：量測大氣壓力，換算火箭實時高度與垂直爬升速度。
* **SPI 通訊模式**：SPI Mode 3 或 Mode 0。
* **備註**：因晶片缺料，本專案將原先設計的 BMP390 替代為 **BMP388**。兩者實體引腳 (Pinout) 與通訊暫存器操作高度一致，均支援 SPI/I2C 介面，暫存器補償公式相似，開發時可通用。
* **核心參數**：
  * 量測範圍：300hPa 至 1250hPa (相當於海拔 -500米 至 +9000米)。
  * 相對精度：±0.08 hPa (等同於 ±0.66 米)。
  * 驅動公式：同樣必須先讀取晶片內部的非易失性校準係數 (Calib Coefficients)，並套用官方的補償公式進行實時計算。

### 4.3 ADXL375 高G值三軸加速度計
* **功能**：火箭起飛瞬間與火箭引擎燃燒時的高衝擊力（High-G）監測。
* **SPI 通訊模式**：SPI Mode 3。
* **量程與動態範圍**：
  * 測量範圍：固定為 **±200g**。
  * 解析度：10-bit，靈敏度為 49mg/LSB (每個 LSB 代表 49 毫克加速度)。
  * 輸出速率：最高支援 3200Hz。

### 4.4 MMC5983MA 三軸地磁計
* **功能**：高精度羅盤，提供航向角輔助基準。
* **I2C 位址**：`0x30` (7-bit address)。
* **規格參數**：
  * 動態範圍：±8 Gauss (高達 ±8 高斯測量範圍)。
  * 解析度：18-bit，極低噪聲。
  * 內建自我消磁機制（SET/RESET 功能），需定期觸發以防止磁化飽和。

### 4.5 W25Q128 快閃記憶體 (Flash)
* **功能**：火箭黑盒子，用於儲存高頻率姿態、高度及通訊遙測 Log。
* **儲存容量**：128M-bit (16M-Byte)。
* **結構組成**：256 頁 (Pages)/扇區 (Sector)，每個扇區為 4KB；每個區塊 (Block) 為 64KB。
* **防寫鎖定**：寫入前必須先發送 `0x06` (Write Enable) 命令，且寫入必須以 4KB 扇區為單位先擦除，再以 256 位元組為單位寫入。

---

## 5. 電源軌與電池電壓監測 (Power System)

### 5.1 電源路徑控制 (PowerPath)
本板整合了 **LTC4412 雙電源自動切換晶片** 與 P-MOSFET 控制：
* **USB 5V 插入時**：`SUP_STAT` (Pin 16 / PC1) 輸出會被拉低（Low），此時板載 MOSFET 會自動阻斷電池供電路徑，由 `+USB_5V` 進行系統供電。
* **USB 拔除時**：`SUP_STAT` 變為高阻態/上拉狀態（High），自動無縫切換回 `V_BAT+`（電池）供電。
* **狀態監測**：韌體可讀取 `PC1` (SUP_STAT) 來得知目前火箭是處於 **地面排針/USB 供電測試狀態 (Low)** 還是 **即將發射的電池供電狀態 (High)**。

### 5.2 電池電壓監測公式
`V_BAT+` 經過電源層的分壓電阻連至 MCU 的 `PC0` (ADC1_IN10)：
* **分壓比例**：`R3 = 1M Ohm` (上拉至 V_BAT+)，`R2 = 100k Ohm` (下拉至 GND)。
* **類比分壓比**：
  $$\text{V\_ADC} = \text{V\_BAT} \times \frac{R_2}{R_3 + R_2} = \text{V\_BAT} \times \frac{100\text{k}}{1\text{M} + 100\text{k}} = \text{V\_BAT} \times \frac{1}{11}$$
* **MCU 讀取計算公式**：
  假設 MCU 的 12-bit ADC 參考電壓為 $V_{\text{ref}} = 3.3\text{V}$，ADC 的數位讀值為 $D_{\text{ADC}}$：
  $$\text{V\_BAT} = 11 \times \left( \frac{D_{\text{ADC}}}{4095} \times 3.3 \right) = \frac{D_{\text{ADC}} \times 36.3}{4095}\text{ Volts}$$

---

## 6. 火箭點火控制機制 (Ignition Control)

火箭的點火與級間分離觸發是藉由 GPIO `PD13` (FIRE) 控制 N-MOSFET (Q5) 實現：
* **驅動原理**：`PD13` 輸出為低電平（GND）時，MOSFET 關閉，點火迴路斷開；當 `PD13` 輸出為高電平（3.3V）時，MOSFET 導通，電池大電流流過點火頭，將其燒毀以點燃引擎。
* **安全程式防護建議**：
  > [!CAUTION]
  > ### ⚠️ 點火安全機制防護警告
  > 為了避免程式重啟、當機或初始化期間引腳抖動導致火箭意外點火：
  > 1. **硬體防護**：`PD13` 上拉/下拉電阻必須在初始化前維持穩定低電平，板上已設置 10k 下拉電阻（R51）拉至 GND。
  > 2. **韌體防護**：系統啟動時，**必須優先且立即將 `PD13` 設為 GPIO 輸出低電平 (LOW)**，嚴禁在初始化完成前開啟中斷或拉高該引腳。
  > 3. **觸發防護**：點火觸發代碼必須實施**雙重狀態鎖（Two-Stage Lock）**。例如必須同時滿足「解鎖指令被接收」與「加速度/高度感測器判定火箭處於待發狀態」時，方可進行點火，且點火脈衝寬度應限制在 500ms ~ 1000ms 之間，通電後立即拉低，以策安全。

---

## 7. 航電系統連線速查地圖 (Peripheral Mapping Map)

以下是為開發人員繪製的快速架構總覽圖：

```mermaid
graph TD
    subgraph MCU_Layer [MCU 層 - STM32F407VGT6]
        MCU["STM32F407VGT6 (代替 F405)<br>LQFP100"]
    end

    subgraph SPI1_Bus [SPI1 總線]
        SPI1_SCK[PA5] --- SPI1_BusLine((SPI1))
        SPI1_MISO[PA6] --- SPI1_BusLine
        SPI1_MOSI[PA7] --- SPI1_BusLine
        SPI1_BusLine === BMP388[BMP388 氣壓計<br>片選 PA4]
        SPI1_BusLine === ADXL375[ADXL375 高G計<br>片選 PC4]
        SPI1_BusLine === W25Q128[W25Q128 Flash<br>片選 PA15]
    end

    subgraph SPI2_Bus [SPI2 總線]
        SPI2_SCK[PB13] --- SPI2_BusLine((SPI2))
        SPI2_MISO[PB14] --- SPI2_BusLine
        SPI2_MOSI[PB15] --- SPI2_BusLine
        SPI2_BusLine === BMI088_A[BMI088 Accel<br>片選 PB12]
        SPI2_BusLine === BMI088_G[BMI088 Gyro<br>片選 PB11]
    end

    subgraph SPI3_Bus [SPI3 總線]
        SPI3_SCK[PB3] --- SPI3_BusLine((SPI3))
        SPI3_MISO[PB4] --- SPI3_BusLine
        SPI3_MOSI[PB5] --- SPI3_BusLine
        SPI3_BusLine === LORA920[E80-900M23S 920M LoRa<br>片選 PD7, 重置 PD5, EXTI4]
    end

    subgraph I2C1_Bus [I2C1 總線]
        I2C1_SCL[PB7 SCL] --- I2C1_BusLine((I2C1))
        I2C1_SDA[PB8 SDA] --- I2C1_BusLine
        I2C1_BusLine === MMC5983MA[MMC5983MA 地磁計<br>中斷 PE12]
    end

    subgraph UART_Buses [序列通訊]
        UART3[UART3 TX=PB10, RX=PD9] === LORA433[E22-400T30S 433M LoRa<br>M0=PD11, M1=PD10, RST=PD12]
        UART6[UART6 TX=PC6, RX=PC7] === GPS[NEO-M9N GPS<br>重置 PA8]
        USART2[USART2 TX=PA2, RX=PA3] === DEBUG[除錯串列埠]
    end

    subgraph Power_System [電源與監測]
        VBAT[V_BAT+] -->|分壓 1/11| PC0[PC0 Battery_Sensing]
        LTC4412[LTC4412 PowerPath] -->|STAT 狀態| PC1[PC1 SUP_STAT]
    end

    subgraph Control_Lines [控制引腳]
        PD13[PD13 FIRE] -->|MOSFET 驅動| IGN[點火頭/觸發迴路]
        PA0[PA0 Buzzer] -->|有源| BZ[蜂鳴器]
        PE2_4[PE2/3/4 LED] -->|LED_SYS/1/2| LED[三色 LED 指示燈]
    end

    subgraph SD_Card [SDIO 存儲]
        SDIO[SDIO D0~D3=PC8~PC11, CK=PC12, CMD=PD2] === SD_Slot[MicroSD 卡槽]
        PD3[PD3 SDIO_DET] === SD_Slot
    end
```

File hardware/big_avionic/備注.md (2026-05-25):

# BigAvionic (主航電板) 開發備註與進度

## 📌 專案簡介
`BigAvionic` 是本次火箭發射的主航電板（Avionics Board），主要負責飛行數據處理、感測器數據採集、無線電遙測（LoRa 傳輸）與整體系統的主控調度。硬體設計採用了先進的四層疊板設計（MCU主控層、LoRa收發層、電源分配層、頂層接口板）。

> 💡 **預算優化公告**：
> 1. **首批打樣送印**：由於成本考量，主航電的四個板層：**`newpower`** (電源層)、**`lora`** (通訊層)、**`mainmcu`** (主控層)、**`top`** (頂層接口) 已全數送往工廠進行印製打樣。
> 2. **雙重用途**：此 `BigAvionic` 四層疊板組裝件也將**直接作為地面接收接收站 (GroundStation)** 硬件使用，無須額外開發獨立地面站 PCB！
> 3. **二合一合併板**：我們研發了 **`Production_MCU_TOP_2_in_1`**（由 `top layer` 與 `mcu` 二合一合成的合併板），作為未來量產或高度整合時的低成本備選方案（可少印製一張板子）。

## 🛠️ 硬體/軟體設計要點
* **核心處理器**：採用 STM32F4 系列高能效 MCU（已建立 [bigav407.ioc](file:///Users/laizhiquan/coding/RocketCom/BigAvionic/bigav407.ioc) 作為 STM32CubeMX 專案配置檔，為後續韌體整合測試做好準備）。
* **無線電遙測 (LoRa)**：
  * LoRa 模組採用 E80 系列（E80-900M2213S，參考相關零件庫與規格書）。
  * 需要注意高頻走線、天線阻抗匹配（50 歐姆）以及充足的接地面積。
* **感測器配置**：
  * 氣壓計/高度計：`BMP390` (I2C/SPI 界面，注意避免強光直射氣壓孔與排氣設計)
  * 高重力加速度計：`ADXL375` (±200g，用於發射起飛大加速度採集，建議靠近板子剛度最強處擺放)
  * 慣性測量單元 (IMU)：`BMI088` (六軸高溫穩定度 IMU)
  * 電子羅盤 (地磁計)：`MMC5983MA` (避開大電流導線、電池與電感等強磁干擾源)
  * GPS 定位：`NEO-M9N` (配有主動/被動天線電路設計)
* **資料儲存**：
  * SPI NOR Flash：`W25Q128` (128Mb 快閃記憶體，用於高速飛行日誌記錄)
* **電源架構**：
  * 配有 LTC4412 理想二極體電源切換電路，自動切換外部 USB 與火箭電池。
  * 採用 TPS54538 等高效率 DCDC 降壓晶片提供穩定的 5V/3.3V 電源輸出。

## 📅 開發與整合進度表
- `[x]` **階段一：參考規格書與電路庫整理** (Done)
- `[x]` **階段二：四層疊板送印打樣** (`newpower`, `lora`, `mainmcu`, `top`) (Done)
- `[x]` **階段三：二合一合併板 `Production_MCU_TOP_2_in_1` 封裝與更名** (Done)
- `[ ]` **階段四：首板打樣與硬體調試**
  - `[x]` **頂層接口板 (Top Layer) 測試成功**：成功利用 Arduino 測試平台 (ESP32) 讀取 I2C 磁力計與解析 GPS，硬體介面通信運作完美！(Done)
  - `[ ]` 手工焊接元件，確認電源軌紋波正常
  - `[ ]` 點亮最小系統板，燒錄基本閃燈程式
- `[ ]` **階段五：韌體開發與數據採集測試** (等待主板與 STM32 韌體整合)

## 📝 備註與已知問題紀錄
* **2026-05-25**：硬體測試里程碑！**頂層接口板 (Top Layer) 成功與 Arduino 整合測試**，並在 `arduino_test_code/gps_mag_sync/` 下提供了完整的 I2C 磁力計與 UART2 GPS 同步數據流測試代碼。目前等待發廠打樣，並進入 STM32 韌體整合準備。
* **2026-05-25**：完成 `Production_MCU_TOP_2_in_1` 的正名與檔案對齊。確認 4 個疊板層均已發廠打樣。

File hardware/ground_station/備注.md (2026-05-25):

# GroundStation (地面接收站) 開發備註與進度

## 📌 專案簡介
`GroundStation` 為地面接收站專案。

> ⚠️ **預算與開發策略重大調整**：
> * **硬體完美複用**：為極大化節約開發與生產成本，原定獨立設計的地面接收站 PCB 板**全面取消送印打樣**。
> * **全功能替代方案**：我們將**直接使用一套完整組裝的 `BigAvionic` 四層疊板**作為地面站接收硬體！
>   * 由於 `BigAvionic` 本身已集成高性能 STM32F4 主控晶片、E80 系列 LoRa 遙測通訊模組，以及 USB 串口傳輸界面，其硬體功能已完全覆蓋地面接收與數據回傳的全部需求！
>   * 組員無須重複畫板與焊接地面站，直接利用相同硬體燒錄接收站韌體即可工作！
> * **本目錄功能變更**：本目錄下的舊版 KiCad 專案僅保留作為**技術備份與存檔**。

---

## 📅 開發與整合進度表
- `[x]` **階段一：無線收發硬體與通訊協議設計** (Done)
- `[x]` **階段二：宣告直接使用 `BigAvionic` 四層疊板作為地面接收硬體，節省打樣成本** (Done)
- `[ ]` **階段三：地面站數據接收與上位機通訊韌體開發** (利用 `BigAvionic` 硬體)
  - `[ ]` 基於 STM32CubeMX 配置文件 (`GroundStation_MX.ioc`)，生成接收站主控代碼
  - `[ ]` 實作 LoRa 接收端數據包校驗與打包
  - `[ ]` 實作 USB-TTL 的串口輸出協定
- `[ ]` **階段四：上位機實時繪圖界面 (GUI Dashboard) 開發**
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

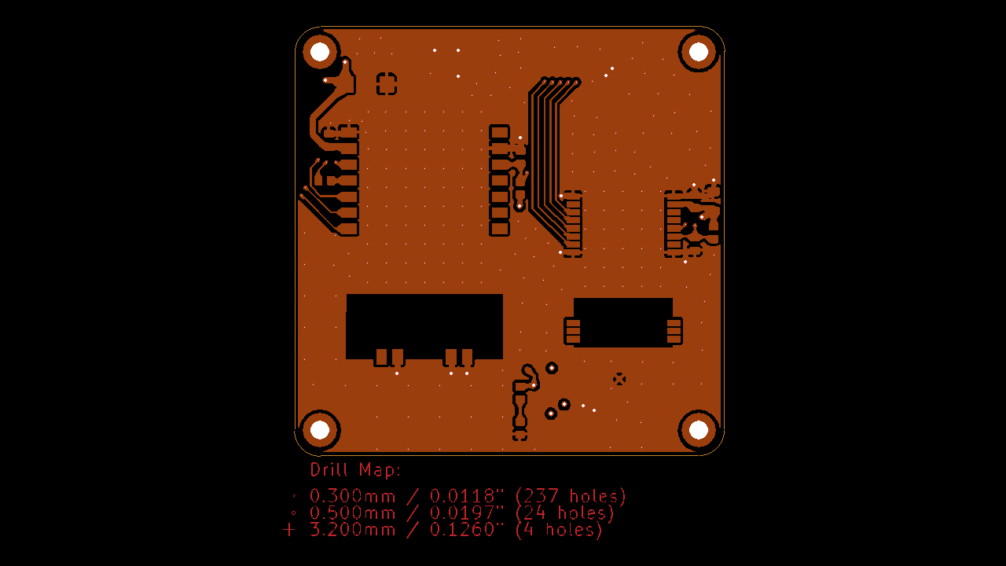
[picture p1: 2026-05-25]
hardware/big_avionic/lora/12421607a_y11/yg/GBR_11415079_1_snapshot.png

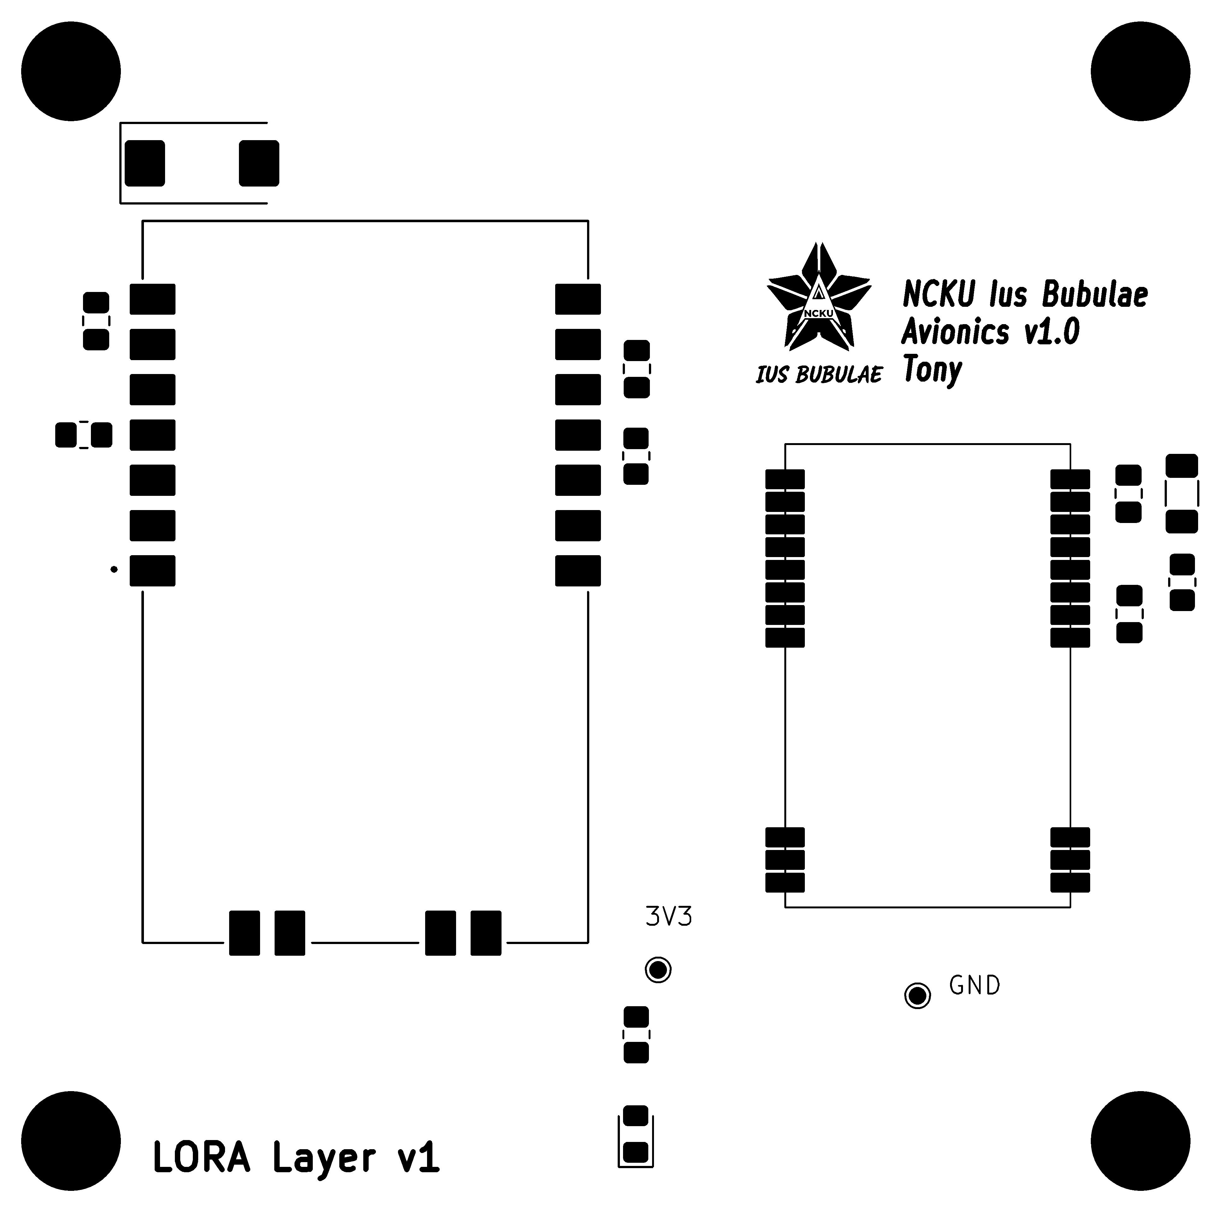
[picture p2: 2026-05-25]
hardware/big_avionic/lora/12421607a_y11/yg/GBR_11415079_1_top.png

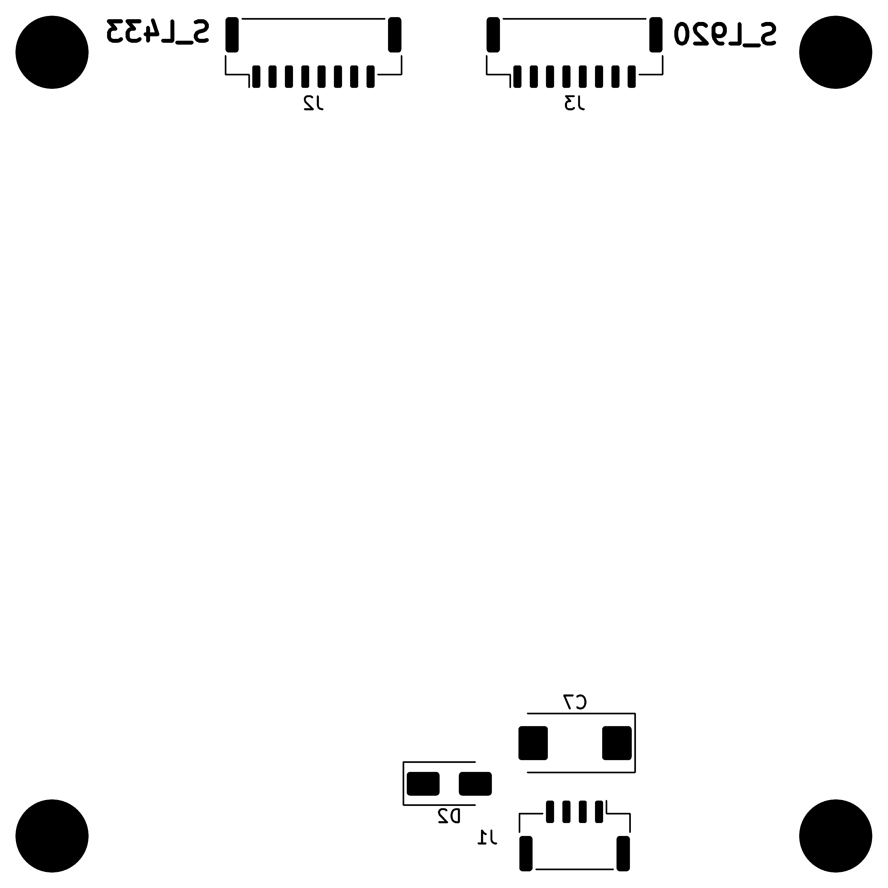
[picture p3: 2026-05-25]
hardware/big_avionic/lora/12421607a_y11/yg/GBR_11415079_1_bottom.png

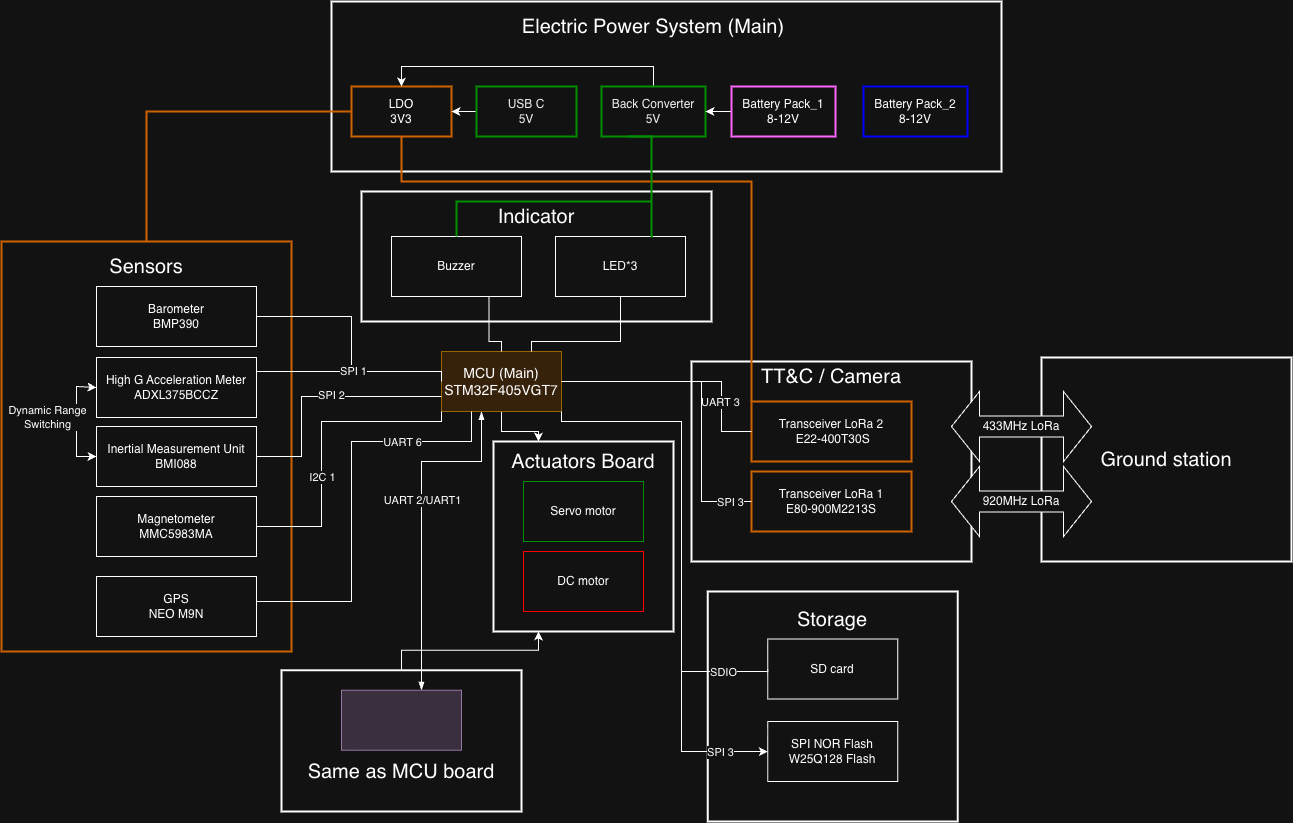
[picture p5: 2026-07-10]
documentation/presentations/BigAvionic_Bus_plan.png

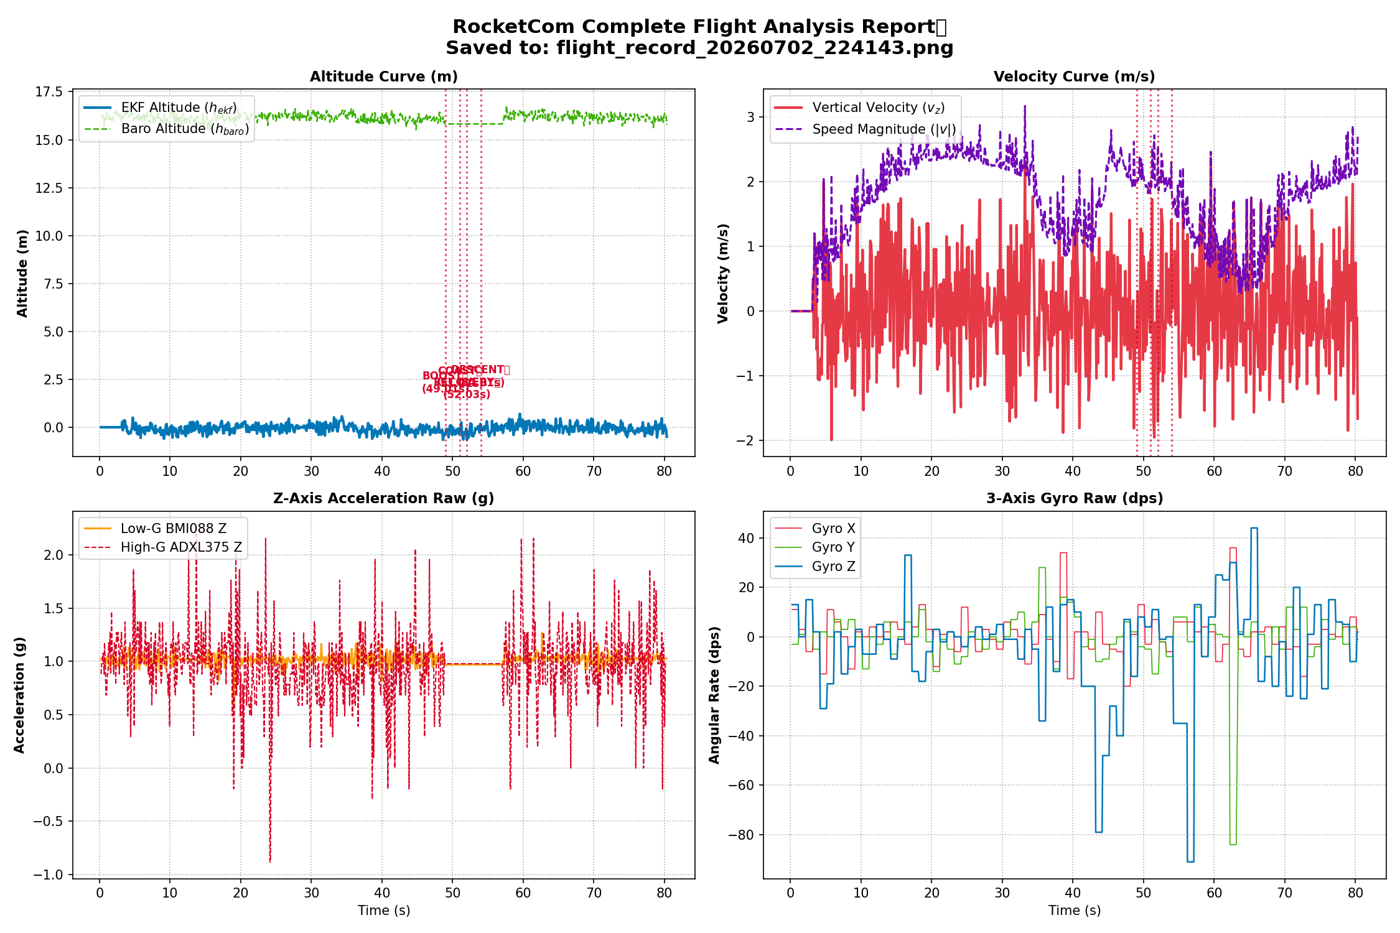
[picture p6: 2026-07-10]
simulation_and_data/flight_plots/flight_record_20260702_224143.png

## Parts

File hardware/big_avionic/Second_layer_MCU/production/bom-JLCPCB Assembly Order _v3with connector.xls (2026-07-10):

JLCPCB BOM Tool - BOM Matching
BOM name：bom-JLCPCB Assembly Order.xlsx |  |  | Download Time：2026-05-01 01:15:27 |  |  |  | * Our matching results are updated in real-time, but stock and prices may change. If it's been over 24 hours, please re-match before placing your order.
PCB Assembled Qty：5 |  |  | Est. Total Price：137.1799
Your BOM |  |  |  |  | Matched Parts |  |  |  |  |  |  | Order Information
Top Designator | Bottom Designator | Comment | Footprint | JLCPCB Part # | Matches | Part # | Manufacturer | Footprint | Description | Category | Warning | JLCPCB Part # | Product link | Lib Type | Qty | Source | Total Price ($)
C1,C19 | C12 | 10u | 0805 |  | Unconfirmed | GRM21BR61H106KE43L | Murata Electronics | 0805 | 10uF 50V X5R ±10% 0805 Multilayer Ceramic Capacitors MLCC - SMD/SMT ROHS | Multilayer Ceramic Capacitors MLCC - SMD/SMT | 1.The comment (GRM21BR61H106KE43L) of this part does not match the one (10u) provided in your BOM. Please confirm; | C440198 | https://jlcpcb.com/partdetail/439567-GRM21BR61H106KE43L/C440198 | Basic | 20 | 20 JLCPCB | 1.356
C8,C9 |  | 2.2u | 0805 |  | Unconfirmed | CL21A225KBQNNNE | Samsung Electro-Mechanics | 0805 | 2.2uF 50V X5R ±10% 0805 Multilayer Ceramic Capacitors MLCC - SMD/SMT ROHS | Multilayer Ceramic Capacitors MLCC - SMD/SMT | 1.The comment (CL21A225KBQNNNE) of this part does not match the one (2.2u) provided in your BOM. Please confirm; | C377773 | https://jlcpcb.com/partdetail/350246-CL21A225KBQNNNE/C377773 | Basic | 20 | 20 JLCPCB | 0.358
C10,C11,C15,C2,C20,C22,C23,C26,C28,C29,C3,C4,C5,C6,C7 | C13,C24,C25,C27 | 100n | 0402 |  | Unconfirmed | CL05B104KO5NNNC | Samsung Electro-Mechanics | 0402 | 100nF 16V X7R ±10% 0402 Multilayer Ceramic Capacitors MLCC - SMD/SMT ROHS | Multilayer Ceramic Capacitors MLCC - SMD/SMT | 1.The comment (CL05B104KO5NNNC) of this part does not match the one (100n) provided in your BOM. Please confirm; | C1525 | https://jlcpcb.com/partdetail/1877-CL05B104KO5NNNC/C1525 | Basic | 96 | 96 JLCPCB | 0.1248
C14 |  | 1n | 0402 |  | Unconfirmed | 0402B102K500NT | FH (Guangdong Fenghua Advanced Tech) | 0402 | 1nF 50V X7R ±10% 0402 Multilayer Ceramic Capacitors MLCC - SMD/SMT ROHS | Multilayer Ceramic Capacitors MLCC - SMD/SMT | 1.The comment (0402B102K500NT) of this part does not match the one (1n) provided in your BOM. Please confirm; | C1523 | https://jlcpcb.com/partdetail/1875-0402B102K500NT/C1523 | Basic | 20 | 20 JLCPCB | 0.026
C16 |  | 1u | 0402 |  | Unconfirmed | CL05A105KA5NQNC | Samsung Electro-Mechanics | 0402 | 1uF 25V X5R ±10% 0402 Multilayer Ceramic Capacitors MLCC - SMD/SMT ROHS | Multilayer Ceramic Capacitors MLCC - SMD/SMT | 1.The comment (CL05A105KA5NQNC) of this part does not match the one (1u) provided in your BOM. Please confirm; | C52923 | https://jlcpcb.com/partdetail/53938-CL05A105KA5NQNC/C52923 | Basic | 20 | 20 JLCPCB | 0.078
C17,C18 |  | 10pF | 0603 |  | Select by System | CL10C100JB8NNNC | Samsung Electro-Mechanics | 0603 | 10pF 50V C0G ±5% 0603 Multilayer Ceramic Capacitors MLCC - SMD/SMT ROHS | Multilayer Ceramic Capacitors MLCC - SMD/SMT |  | C1634 | https://jlcpcb.com/partdetail/1986-CL10C100JB8NNNC/C1634 | Basic | 20 | 20 JLCPCB | 0.098
 | C21 | 4.7u | 0805 |  | Unconfirmed | CL21A475KAQNNNE | Samsung Electro-Mechanics | 0805 | 25V 4.7uF X5R ±10% 0805 Multilayer Ceramic Capacitors MLCC - SMD/SMT ROHS | Multilayer Ceramic Capacitors MLCC - SMD/SMT | 1.The comment (CL21A475KAQNNNE) of this part does not match the one (4.7u) provided in your BOM. Please confirm; | C1779 | https://jlcpcb.com/partdetail/2131-CL21A475KAQNNNE/C1779 | Basic | 20 | 20 JLCPCB | 0.272
 | C30,C31 | 22u | 1206 |  | Unconfirmed | CL31A226KAHNNNE | Samsung Electro-Mechanics | 1206 | 22uF 25V X5R ±10% 1206 Multilayer Ceramic Capacitors MLCC - SMD/SMT ROHS | Multilayer Ceramic Capacitors MLCC - SMD/SMT | 1.The comment (CL31A226KAHNNNE) of this part does not match the one (22u) provided in your BOM. Please confirm; | C12891 | https://jlcpcb.com/partdetail/13537-CL31A226KAHNNNE/C12891 | Basic | 12 | 12 JLCPCB | 0.6744
D1 |  | Y | 0805 |  | Select by Customer | KT-0805Y | Hubei KENTO Elec | 0805 | -40℃~+85℃ 1.8V~2.4V 120° 175mcd 40mW 584nm~594nm 596nm Discrete Diode Water Clear Yellow 0805 LED Indication - Discrete ROHS | LED Indication - Discrete |  | C2296 | https://jlcpcb.com/partdetail/Hubei_KENTOElec-KT0805Y/C2296 | Basic | 20 | 20 JLCPCB | 0.3
D2 |  | G | 0805 |  | Select by Customer | KT-0805G | Hubei KENTO Elec | 0805 | -40℃~+85℃ 100mW 120° 2.6V~3.1V 430mcd 513nm~528nm 525nm 5mA Discrete Diode Emerald Green Water Clear 0805 LED Indication - Discrete ROHS | LED Indication - Discrete |  | C2297 | https://jlcpcb.com/partdetail/Hubei_KENTOElec-KT0805G/C2297 | Basic | 20 | 20 JLCPCB | 0.32
D3 |  | W | 0805 |  | Select by Customer | KT-0805W | Hubei KENTO Elec | 0805 | -30℃~+85℃ 120° 13172K~100000K 2.6V~3.2V 25mA 350mcd 80mW Discrete Diode Top-mount White Yellow Lens 0805 LED Indication - Discrete ROHS | LED Indication - Discrete |  | C34499 | https://jlcpcb.com/partdetail/Hubei_KENTOElec-KT0805W/C34499 | Basic | 20 | 20 JLCPCB | 0.396
D4 |  | 1N4148 | D_SOD-123 |  | Unconfirmed | 1N4148W | ST(Semtech) | SOD-123 | 150mA 1A 1V@50mA 1uA@75V 400mW 4ns 75V Independent SOD-123 Switching Diodes ROHS | Switching Diodes | 1.The comment (1N4148W) of this part does not match the one (1N4148) provided in your BOM. Please confirm; | C81598 | https://jlcpcb.com/partdetail/ST_Semtech-1N4148W/C81598 | Basic | 15 | 15 JLCPCB | 0.1665
FB1 |  | FerriteBead120R@100M | 0805 |  | Select by Customer | GZ2012D101TF | Sunlord | 0805 | 1 100Ω@100MHz 150mΩ 800mA ±25% 0805 Ferrite Beads ROHS | Ferrite Beads |  | C1015 | https://jlcpcb.com/partdetail/Sunlord-GZ2012D101TF/C1015 | Basic | 20 | 20 JLCPCB | 0.4
J2 |  | USB_C_Receptacle_USB2.0_16P | USB_C_Receptacle_HRO_TYPE-C-31-M-12 |  | Select by Customer | TYPE-C-31-M-12 | Korean Hroparts Elec | SMD | -30℃~+80℃ 1 10,000 cycles 16P 20V 5A 7.35mm Female Surface Mount, Right Angle Type-C SMD USB Connectors ROHS | USB Connectors |  | C165948 | https://jlcpcb.com/partdetail/Korean_HropartsElec-TYPE_C_31_M12/C165948 | Extended | 4 | 4 JLCPCB | 0.7312
J4 |  | Micro_SD_Card_Det1 | microSD_HC_Molex_104031-0811 |  | Select by Customer | 1040310811 | MOLEX | SMD | -25℃~+85℃ 1.42mm Connector and Ejector MicroSD Card (TF Card) Push-Pull SMD SD Card / Memory Card Connector ROHS | SD Card / Memory Card Connector |  | C585350 | https://jlcpcb.com/partdetail/MOLEX-1040310811/C585350 | Extended | 4 | 4 JLCPCB | 2.482
J13,J14,J9 |  | Conn_01x08 | JST_GH_SM08B-GHS-TB_1x08-1MP_P1.25mm_Horizontal |  | Select by Customer | SM08B-GHS-TB(LF)(SN) | JST | SMD,P=1.25mm,卧贴 | -25℃~+85℃ 1 1.25mm 13.25mm 1A 1x8P 4.13mm 4.25mm 50V 8 8P Auxiliary Solder Pin GH PA9T Phosphor bronze Surface Mount, Right Angle Tin UL94V-0 White SMD,P=1.25mm,卧贴 Wire To Board Connector ROHS | Wire To Board Connector |  | C265111 | https://jlcpcb.com/partdetail/JST-SM08B_GHS_TB_LF_SN/C265111 | Extended | 12 | 12 JLCPCB | 3.336
J8 | J10,J11,J5 | Conn_01x04 | JST_GH_SM04B-GHS-TB_1x04-1MP_P1.25mm_Horizontal |  | Select by Customer | XY-SM04B-GHS-TB | XYECONN | SMD,P=1.25mm,卧贴 | -25℃~+85℃ 1 1.25mm 1A 1x4P 250V 4 4P Brass LCP Surface Mount, Right Angle Tin UL94V-0 SMD,P=1.25mm,卧贴 Wire To Board Connector ROHS |  |  | C51940118 | https://jlcpcb.com/partdetail/XYECONN-XY_SM04B_GHSTB/C51940118 | Extended | 16 | 16 JLCPCB | 0.904
Q2 |  | AO3400A | SOT-23 |  | Select by System | AO3400A | Alpha & Omega Semicon | SOT-23 | -55℃~+150℃ 1 N-channel 1.45V 1.4W 30V 48mΩ@2.5V 5.7A 50pF 630pF 75pF 7nC@10V N-Channel SOT-23 MOSFETs ROHS | MOSFETs |  | C20917 | https://jlcpcb.com/partdetail/Alpha_OmegaSemicon-AO3400A/C20917 | Basic | 8 | 8 JLCPCB | 0.6536
R1 |  | 100k | 0402 |  | Unconfirmed | 0402WGF1003TCE | UNI-ROYAL(Uniroyal Elec) | 0402 | -55℃~+155℃ 100kΩ 50V 62.5mW Thick Film Resistor ±1% ±100ppm/℃ 0402 Chip Resistor - Surface Mount ROHS | Chip Resistor - Surface Mount | 1.The comment (0402WGF1003TCE) of this part does not match the one (100k) provided in your BOM. Please confirm; | C25741 | https://jlcpcb.com/partdetail/26484-0402WGF1003TCE/C25741 | Basic | 20 | 20 JLCPCB | 0.018
R2,R3 |  | 5.1k | 0402 |  | Unconfirmed | 0402WGF5101TCE | UNI-ROYAL(Uniroyal Elec) | 0402 | -55℃~+155℃ 5.1kΩ 50V 62.5mW Thick Film Resistor ±1% ±100ppm/℃ 0402 Chip Resistor - Surface Mount ROHS | Chip Resistor - Surface Mount | 1.The comment (0402WGF5101TCE) of this part does not match the one (5.1k) provided in your BOM. Please confirm; | C25905 | https://jlcpcb.com/partdetail/26648-0402WGF5101TCE/C25905 | Basic | 20 | 20 JLCPCB | 0.018
R4,R5 |  | 4.7k | 0402 |  | Unconfirmed | 0402WGF4701TCE | UNI-ROYAL(Uniroyal Elec) | 0402 | -55℃~+155℃ 4.7kΩ 50V 62.5mW Thick Film Resistor ±1% ±100ppm/℃ 0402 Chip Resistor - Surface Mount ROHS | Chip Resistor - Surface Mount | 1.The comment (0402WGF4701TCE) of this part does not match the one (4.7k) provided in your BOM. Please confirm; | C25900 | https://jlcpcb.com/partdetail/26643-0402WGF4701TCE/C25900 | Basic | 20 | 20 JLCPCB | 0.02
R12,R16,R18,R24,R26,R31,R35 | R10,R11,R13,R14,R15,R20,R21,R22,R23,R25 | 10k | 0402 |  | Unconfirmed | 0402WGF1002TCE | UNI-ROYAL(Uniroyal Elec) | 0402 | -55℃~+155℃ 10kΩ 50V 62.5mW Thick Film Resistor ±1% ±100ppm/℃ 0402 Chip Resistor - Surface Mount ROHS | Chip Resistor - Surface Mount | 1.The comment (0402WGF1002TCE) of this part does not match the one (10k) provided in your BOM. Please confirm; | C25744 | https://jlcpcb.com/partdetail/26487-0402WGF1002TCE/C25744 | Basic | 88 | 88 JLCPCB | 0.1144
R17,R19,R32,R6,R7,R8,R9 | R33 | 22ohm | 0402 |  | Unconfirmed | 0402WGF220JTCE | UNI-ROYAL(Uniroyal Elec) | 0402 | -55℃~+155℃ 22Ω 50V 62.5mW Thick Film Resistor ±1% ±100ppm/℃ 0402 Chip Resistor - Surface Mount ROHS | Chip Resistor - Surface Mount | 1.The comment (0402WGF220JTCE) of this part does not match the one (22ohm) provided in your BOM. Please confirm; | C25092 | https://jlcpcb.com/partdetail/25835-0402WGF220JTCE/C25092 | Basic | 58 | 58 JLCPCB | 0.0638
R27 |  | 220 | 0603 |  | Unconfirmed | 0603WAF2200T5E | UNI-ROYAL(Uniroyal Elec) | 0603 | -55℃~+155℃ 100mW 220Ω 75V Thick Film Resistor ±1% ±100ppm/℃ 0603 Chip Resistor - Surface Mount ROHS | Chip Resistor - Surface Mount | 1.The comment (0603WAF2200T5E) of this part does not match the one (220) provided in your BOM. Please confirm; | C22962 | https://jlcpcb.com/partdetail/23689-0603WAF2200T5E/C22962 | Basic | 20 | 20 JLCPCB | 0.03
R28,R29 |  | 100 | 0603 |  | Unconfirmed | 0603WAF1000T5E | UNI-ROYAL(Uniroyal Elec) | 0603 | -55℃~+155℃ 100mW 100Ω 75V Thick Film Resistor ±1% ±100ppm/℃ 0603 Chip Resistor - Surface Mount ROHS | Chip Resistor - Surface Mount | 1.The comment (0603WAF1000T5E) of this part does not match the one (100) provided in your BOM. Please confirm; | C22775 | https://jlcpcb.com/partdetail/23502-0603WAF1000T5E/C22775 | Basic | 20 | 20 JLCPCB | 0.038
R30 |  | 1k | 0402 |  | Unconfirmed | 0402WGF1001TCE | UNI-ROYAL(Uniroyal Elec) | 0402 | -55℃~+155℃ 1kΩ 50V 62.5mW Thick Film Resistor ±1% ±100ppm/℃ 0402 Chip Resistor - Surface Mount ROHS | Chip Resistor - Surface Mount | 1.The comment (0402WGF1001TCE) of this part does not match the one (1k) provided in your BOM. Please confirm; | C11702 | https://jlcpcb.com/partdetail/12256-0402WGF1001TCE/C11702 | Basic | 20 | 20 JLCPCB | 0.02
U1 |  | STM32F405VGTx | LQFP-100_14x14mm_P0.5mm |  | Select by Customer | STM32F405VGT6 | STMicroelectronics | LQFP-100(14x14) | -40℃~+85℃ 1.8V~3.6V 12bit 12bit 168MHz 192KB 1MB 32 Bit 82 ARM Cortex-M4 Built-in FLASH LQFP-100(14x14) Microcontrollers (MCU/MPU/SOC) ROHS | Microcontrollers (MCU/MPU/SOC) |  | C56621 | https://jlcpcb.com/partdetail/STMicroelectronics-STM32F405VGT6/C56621 | Extended | 4 | 4 JLCPCB | 27.292
 | U2 | W25Q128JVS | SOIC-8_5.3x5.3mm_P1.27mm |  | Unconfirmed | W25Q128JVSIQ | Winbond Elec | SOIC-8-208mil | -40℃~+85℃ 100,000 cycles 120ms@(32KB) 128Mbit 133MHz 1uA 2.7V~3.6V 20 Years 3ms SPI SOIC-8-208mil NOR FLASH ROHS | NOR FLASH | 1.The comment (W25Q128JVSIQ) of this part does not match the one (W25Q128JVS) provided in your BOM. Please confirm; | C97521 | https://jlcpcb.com/partdetail/WinbondElec-W25Q128JVSIQ/C97521 | Basic | 4 | 4 JLCPCB | 7.5536
U3 |  | ADXL375BCCZ | LGA_CC-14-1_ADI-L |  | Select by Customer | ADXL375BCCZ-RL7 | Analog Devices | LGA-14(3x5) | -40℃~+85℃ 100nA 16bit 2V~3.6V Accelerometer SPI、I2C X,Y,Z ±200g LGA-14(3x5) Accelerometers ROHS | Accelerometers | 1.The comment (ADXL375BCCZ-RL7) of this part does not match the one (ADXL375BCCZ) provided in your BOM. Please confirm; | C481898 | https://jlcpcb.com/partdetail/AnalogDevices-ADXL375BCCZRL7/C481898 | Extended | 4 | 4 JLCPCB | 38.5136
U4 |  | BMP388/390 | 10LGA_2X2X0p75_BOS-M |  | Select by Customer | BMP388 | Bosch Sensortec | LGA-10(2x2) | -40℃~+85℃ 1.65V~3.6V 1pa/K 2uA 30Kpa~1.25bar 50pa 8pa I2C、SPI LGA-10(2x2) Pressure Sensors ROHS | Pressure Sensors |  | C779278 | https://jlcpcb.com/partdetail/BoschSensortec-BMP388/C779278 | Extended | 4 | 4 JLCPCB | 11.8152
 | U5 | BMI088 | Bosch_LGA-16_4.5x3mm_P0.5mm_LayoutBorder7x1y_ClockwisePinNumbering |  | Select by System | BMI088 | Bosch Sensortec | LGA-16(3x4.5) | -40℃~+85℃ Accelerometer Gyroscope LGA-16(3x4.5) Accelerometers ROHS | Accelerometers |  | C194919 | https://jlcpcb.com/partdetail/BoschSensortec-BMI088/C194919 | Extended | 4 | 4 JLCPCB | 38.4372
Y1 |  | FA-23816Mhz | Crystal_SMD_SeikoEpson_FA238-4Pin_3.2x2.5mm |  | Select by Customer | X322516MLB4SI | YXC Crystal Oscillators | SMD3225-4P | -40℃~+85℃ 16MHz 9pF Crystal Oscillator ±10ppm ±20ppm SMD3225-4P Crystals ROHS | Crystals |  | C13738 | https://jlcpcb.com/partdetail/YXC_CrystalOscillators-X322516MLB4SI/C13738 | Basic | 8 | 8 JLCPCB | 0.5696
BZ1 |  | ActiveBuzzer | MagneticBuzzer_CUI_CMT-8504-100-SMT |  | No matches | No Part Selected
J1,J6 |  | Conn_01x04 | PinHeader_1x04_P2.54mm_Vertical |  | No matches | No Part Selected
J3 |  | Conn_01x02 | PinHeader_1x02_P2.54mm_Vertical |  | No matches | No Part Selected
J7 |  | Screw_Terminal_01x02 | TerminalBlock_Phoenix_PT-1,5-2-3.5-H_1x02_P3.50mm_Horizontal |  | No matches | No Part Selected
SW1 |  | SW_Push | SW_PUSH_6mm_H4.3mm |  | No matches | No Part Selected
SW2,SW3 |  | SW_Push_Shielded | SW_Push_1P1T-SH_NO_CK_KMR2xxG |  | No matches | No Part Selected

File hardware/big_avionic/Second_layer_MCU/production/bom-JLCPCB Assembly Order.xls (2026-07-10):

JLCPCB BOM Tool - BOM Matching
BOM name：bom-JLCPCB Assembly Order.xlsx |  |  | Download Time：2026-04-30 23:30:04 |  |  |  | * Our matching results are updated in real-time, but stock and prices may change. If it's been over 24 hours, please re-match before placing your order.
PCB Assembled Qty：5 |  |  | Est. Total Price：111.9919
Your BOM |  |  |  |  | Matched Parts |  |  |  |  |  |  | Order Information
Top Designator | Bottom Designator | Comment | Footprint | JLCPCB Part # | Matches | Part # | Manufacturer | Footprint | Description | Category | Warning | JLCPCB Part # | Product link | Lib Type | Qty | Source | Total Price ($)
BZ1 |  | ActiveBuzzer | MagneticBuzzer_CUI_CMT-8504-100-SMT |  | Select by Customer | CMT-8504-100-SMT-TR | CUI | SMD,8.5x8.5mm | -40℃~+85℃ 100dB 150mA 1V~6V 4kHz 4mm 5V 8.5mm 8.5mm Electromagnetic Passive (Externally Driven) SMD SMD,8.5x8.5mm Buzzers ROHS | Buzzers |  | C22359707 | https://jlcpcb.com/partdetail/CUI-CMT_8504_100_SMTTR/C22359707 | Extended | 3 | 3 JLCPCB | 8.1342
C1,C19 | C12 | 10u | 0805 |  | Unconfirmed | GRM21BR61H106KE43L | Murata Electronics | 0805 | 10uF 50V X5R ±10% 0805 Multilayer Ceramic Capacitors MLCC - SMD/SMT ROHS | Multilayer Ceramic Capacitors MLCC - SMD/SMT | 1.The comment (GRM21BR61H106KE43L) of this part does not match the one (10u) provided in your BOM. Please confirm; | C440198 | https://jlcpcb.com/partdetail/439567-GRM21BR61H106KE43L/C440198 | Basic | 17 | 17 JLCPCB | 1.1526
C8,C9 |  | 2.2u | 0805 |  | Unconfirmed | CL21A225KBQNNNE | Samsung Electro-Mechanics | 0805 | 2.2uF 50V X5R ±10% 0805 Multilayer Ceramic Capacitors MLCC - SMD/SMT ROHS | Multilayer Ceramic Capacitors MLCC - SMD/SMT | 1.The comment (CL21A225KBQNNNE) of this part does not match the one (2.2u) provided in your BOM. Please confirm; | C377773 | https://jlcpcb.com/partdetail/350246-CL21A225KBQNNNE/C377773 | Basic | 20 | 20 JLCPCB | 0.358
C10,C11,C15,C2,C20,C22,C23,C26,C28,C29,C3,C4,C5,C6,C7 | C13,C24,C25,C27 | 100n | 0402 |  | Unconfirmed | CL05B104KO5NNNC | Samsung Electro-Mechanics | 0402 | 100nF 16V X7R ±10% 0402 Multilayer Ceramic Capacitors MLCC - SMD/SMT ROHS | Multilayer Ceramic Capacitors MLCC - SMD/SMT | 1.The comment (CL05B104KO5NNNC) of this part does not match the one (100n) provided in your BOM. Please confirm; | C1525 | https://jlcpcb.com/partdetail/1877-CL05B104KO5NNNC/C1525 | Basic | 77 | 77 JLCPCB | 0.1001
C14 |  | 1n | 0402 |  | Unconfirmed | 0402B102K500NT | FH (Guangdong Fenghua Advanced Tech) | 0402 | 1nF 50V X7R ±10% 0402 Multilayer Ceramic Capacitors MLCC - SMD/SMT ROHS | Multilayer Ceramic Capacitors MLCC - SMD/SMT | 1.The comment (0402B102K500NT) of this part does not match the one (1n) provided in your BOM. Please confirm; | C1523 | https://jlcpcb.com/partdetail/1875-0402B102K500NT/C1523 | Basic | 20 | 20 JLCPCB | 0.026
C16 |  | 1u | 0402 |  | Unconfirmed | CL05A105KA5NQNC | Samsung Electro-Mechanics | 0402 | 1uF 25V X5R ±10% 0402 Multilayer Ceramic Capacitors MLCC - SMD/SMT ROHS | Multilayer Ceramic Capacitors MLCC - SMD/SMT | 1.The comment (CL05A105KA5NQNC) of this part does not match the one (1u) provided in your BOM. Please confirm; | C52923 | https://jlcpcb.com/partdetail/53938-CL05A105KA5NQNC/C52923 | Basic | 20 | 20 JLCPCB | 0.078
C17,C18 |  | 15pF | 0603 |  | Select by System | CL10C150JB8NNNC | Samsung Electro-Mechanics | 0603 | 15pF 50V C0G ±5% 0603 Multilayer Ceramic Capacitors MLCC - SMD/SMT ROHS | Multilayer Ceramic Capacitors MLCC - SMD/SMT |  | C1644 | https://jlcpcb.com/partdetail/1996-CL10C150JB8NNNC/C1644 | Basic | 20 | 20 JLCPCB | 0.106
 | C21 | 4.7u | 0805 |  | Unconfirmed | CL21A475KAQNNNE | Samsung Electro-Mechanics | 0805 | 25V 4.7uF X5R ±10% 0805 Multilayer Ceramic Capacitors MLCC - SMD/SMT ROHS | Multilayer Ceramic Capacitors MLCC - SMD/SMT | 1.The comment (CL21A475KAQNNNE) of this part does not match the one (4.7u) provided in your BOM. Please confirm; | C1779 | https://jlcpcb.com/partdetail/2131-CL21A475KAQNNNE/C1779 | Basic | 20 | 20 JLCPCB | 0.272
 | C30,C31 | 22u | 1206 |  | Unconfirmed | CL31A226KAHNNNE | Samsung Electro-Mechanics | 1206 | 22uF 25V X5R ±10% 1206 Multilayer Ceramic Capacitors MLCC - SMD/SMT ROHS | Multilayer Ceramic Capacitors MLCC - SMD/SMT | 1.The comment (CL31A226KAHNNNE) of this part does not match the one (22u) provided in your BOM. Please confirm; | C12891 | https://jlcpcb.com/partdetail/13537-CL31A226KAHNNNE/C12891 | Basic | 10 | 10 JLCPCB | 0.562
D1 |  | G | 0805 |  | Select by Customer | KT-0805G | Hubei KENTO Elec | 0805 | -40℃~+85℃ 100mW 120° 2.6V~3.1V 430mcd 513nm~528nm 525nm 5mA Discrete Diode Emerald Green Water Clear 0805 LED Indication - Discrete ROHS | LED Indication - Discrete |  | C2297 | https://jlcpcb.com/partdetail/Hubei_KENTOElec-KT0805G/C2297 | Basic | 20 | 20 JLCPCB | 0.32
D2 |  | R | 0805 |  | Select by Customer | KT-0805R | Hubei KENTO Elec | 0805 | -40℃~+85℃ 120° 2.4V 210mcd 40mW 615nm~630nm 645nm Discrete Diode Red Water Clear 0805 LED Indication - Discrete ROHS | LED Indication - Discrete |  | C2295 | https://jlcpcb.com/partdetail/Hubei_KENTOElec-KT0805R/C2295 | Extended | 20 | 20 JLCPCB | 0.164
D3 |  | B | 0805 |  | Select by Customer | KT-0805B | Hubei KENTO Elec | 0805 | -40℃~+85℃ 100mW 100mcd 120° 3.1V 460nm~475nm 469nm 5mA Blue Discrete Diode Water Clear 0805 LED Indication - Discrete ROHS | LED Indication - Discrete |  | C2293 | https://jlcpcb.com/partdetail/Hubei_KENTOElec-KT0805B/C2293 | Extended | 20 | 20 JLCPCB | 0.242
D4 |  | 1N4148 | D_SOD-123 |  | Unconfirmed | 1N4148W | ST(Semtech) | SOD-123 | 150mA 1A 1V@50mA 1uA@75V 400mW 4ns 75V Independent SOD-123 Switching Diodes ROHS | Switching Diodes | 1.The comment (1N4148W) of this part does not match the one (1N4148) provided in your BOM. Please confirm; | C81598 | https://jlcpcb.com/partdetail/ST_Semtech-1N4148W/C81598 | Basic | 15 | 15 JLCPCB | 0.1665
FB1 |  | FerriteBead120R@100M | 0805 |  | Select by Customer | GZ2012D101TF | Sunlord | 0805 | 1 100Ω@100MHz 150mΩ 800mA ±25% 0805 Ferrite Beads ROHS | Ferrite Beads |  | C1015 | https://jlcpcb.com/partdetail/Sunlord-GZ2012D101TF/C1015 | Basic | 20 | 20 JLCPCB | 0.4
J2 |  | USB_C_Receptacle_USB2.0_16P | USB_C_Receptacle_HRO_TYPE-C-31-M-12 |  | Select by Customer | TYPE-C-31-M-12 | Korean Hroparts Elec | SMD | -30℃~+80℃ 1 10,000 cycles 16P 20V 5A 7.35mm Female Surface Mount, Right Angle Type-C SMD USB Connectors ROHS | USB Connectors |  | C165948 | https://jlcpcb.com/partdetail/Korean_HropartsElec-TYPE_C_31_M12/C165948 | Extended | 3 | 3 JLCPCB | 0.5484
J4 |  | Micro_SD_Card_Det1 | microSD_HC_Molex_104031-0811 |  | Select by Customer | 1040310811 | MOLEX | SMD | -25℃~+85℃ 1.42mm Connector and Ejector MicroSD Card (TF Card) Push-Pull SMD SD Card / Memory Card Connector ROHS | SD Card / Memory Card Connector |  | C585350 | https://jlcpcb.com/partdetail/MOLEX-1040310811/C585350 | Extended | 3 | 3 JLCPCB | 1.8615
J13,J14,J9 |  | Conn_01x08 | JST_GH_SM08B-GHS-TB_1x08-1MP_P1.25mm_Horizontal |  | Select by Customer | SM08B-GHS-TB(LF)(SN) | JST | SMD,P=1.25mm,卧贴 | -25℃~+85℃ 1 1.25mm 13.25mm 1A 1x8P 4.13mm 4.25mm 50V 8 8P Auxiliary Solder Pin GH PA9T Phosphor bronze Surface Mount, Right Angle Tin UL94V-0 White SMD,P=1.25mm,卧贴 Wire To Board Connector ROHS | Wire To Board Connector |  | C265111 | https://jlcpcb.com/partdetail/JST-SM08B_GHS_TB_LF_SN/C265111 | Extended | 9 | 9 JLCPCB | 2.502
J8 | J10,J11,J5 | Conn_01x04 | JST_GH_SM04B-GHS-TB_1x04-1MP_P1.25mm_Horizontal |  | Select by Customer | XY-SM04B-GHS-TB | XYECONN | SMD,P=1.25mm,卧贴 | -25℃~+85℃ 1 1.25mm 1A 1x4P 250V 4 4P Brass LCP Surface Mount, Right Angle Tin UL94V-0 SMD,P=1.25mm,卧贴 Wire To Board Connector ROHS |  |  | C51940118 | https://jlcpcb.com/partdetail/XYECONN-XY_SM04B_GHSTB/C51940118 | Extended | 12 | 12 JLCPCB | 0.678
Q2 |  | BSS138 | SOT-23 |  | Select by System | BSS138 | hongjiacheng | SOT-23 | -55℃~+150℃ 1 N-channel 1.1Ω@10V、1.2Ω@4.5V 1.2V 1.7nC@10V 17.5pF 340mA 350mW 50V 6.5pF N-Channel SOT-23 MOSFETs ROHS | MOSFETs |  | C7420339 | https://jlcpcb.com/partdetail/hongjiacheng-BSS138/C7420339 | Extended | 10 | 10 JLCPCB | 0.174
R1 |  | 100k | 0402 |  | Unconfirmed | 0402WGF1003TCE | UNI-ROYAL(Uniroyal Elec) | 0402 | -55℃~+155℃ 100kΩ 50V 62.5mW Thick Film Resistor ±1% ±100ppm/℃ 0402 Chip Resistor - Surface Mount ROHS | Chip Resistor - Surface Mount | 1.The comment (0402WGF1003TCE) of this part does not match the one (100k) provided in your BOM. Please confirm; | C25741 | https://jlcpcb.com/partdetail/26484-0402WGF1003TCE/C25741 | Basic | 20 | 20 JLCPCB | 0.018
R2,R3 |  | 5.1k | 0402 |  | Unconfirmed | 0402WGF5101TCE | UNI-ROYAL(Uniroyal Elec) | 0402 | -55℃~+155℃ 5.1kΩ 50V 62.5mW Thick Film Resistor ±1% ±100ppm/℃ 0402 Chip Resistor - Surface Mount ROHS | Chip Resistor - Surface Mount | 1.The comment (0402WGF5101TCE) of this part does not match the one (5.1k) provided in your BOM. Please confirm; | C25905 | https://jlcpcb.com/partdetail/26648-0402WGF5101TCE/C25905 | Basic | 20 | 20 JLCPCB | 0.018
R4,R5 |  | 4.7k | 0402 |  | Unconfirmed | 0402WGF4701TCE | UNI-ROYAL(Uniroyal Elec) | 0402 | -55℃~+155℃ 4.7kΩ 50V 62.5mW Thick Film Resistor ±1% ±100ppm/℃ 0402 Chip Resistor - Surface Mount ROHS | Chip Resistor - Surface Mount | 1.The comment (0402WGF4701TCE) of this part does not match the one (4.7k) provided in your BOM. Please confirm; | C25900 | https://jlcpcb.com/partdetail/26643-0402WGF4701TCE/C25900 | Basic | 20 | 20 JLCPCB | 0.02
R12,R16,R18,R24,R26,R31,R35 | R10,R11,R13,R14,R15,R20,R21,R22,R23,R25 | 10k | 0402 |  | Unconfirmed | 0402WGF1002TCE | UNI-ROYAL(Uniroyal Elec) | 0402 | -55℃~+155℃ 10kΩ 50V 62.5mW Thick Film Resistor ±1% ±100ppm/℃ 0402 Chip Resistor - Surface Mount ROHS | Chip Resistor - Surface Mount | 1.The comment (0402WGF1002TCE) of this part does not match the one (10k) provided in your BOM. Please confirm; | C25744 | https://jlcpcb.com/partdetail/26487-0402WGF1002TCE/C25744 | Basic | 71 | 71 JLCPCB | 0.0923
R17,R19,R32,R6,R7,R8,R9 | R33 | 22ohm | 0402 |  | Unconfirmed | 0402WGF220JTCE | UNI-ROYAL(Uniroyal Elec) | 0402 | -55℃~+155℃ 22Ω 50V 62.5mW Thick Film Resistor ±1% ±100ppm/℃ 0402 Chip Resistor - Surface Mount ROHS | Chip Resistor - Surface Mount | 1.The comment (0402WGF220JTCE) of this part does not match the one (22ohm) provided in your BOM. Please confirm; | C25092 | https://jlcpcb.com/partdetail/25835-0402WGF220JTCE/C25092 | Basic | 51 | 51 JLCPCB | 0.0561
R27,R28,R29 |  | 2.2k | 0603 |  | Unconfirmed | 0603WAF2201T5E | UNI-ROYAL(Uniroyal Elec) | 0603 | -55℃~+155℃ 100mW 2.2kΩ 75V Thick Film Resistor ±1% ±100ppm/℃ 0603 Chip Resistor - Surface Mount ROHS | Chip Resistor - Surface Mount | 1.The comment (0603WAF2201T5E) of this part does not match the one (2.2k) provided in your BOM. Please confirm; | C4190 | https://jlcpcb.com/partdetail/4597-0603WAF2201T5E/C4190 | Basic | 20 | 20 JLCPCB | 0.03
R30 |  | 1k | 0402 |  | Unconfirmed | 0402WGF1001TCE | UNI-ROYAL(Uniroyal Elec) | 0402 | -55℃~+155℃ 1kΩ 50V 62.5mW Thick Film Resistor ±1% ±100ppm/℃ 0402 Chip Resistor - Surface Mount ROHS | Chip Resistor - Surface Mount | 1.The comment (0402WGF1001TCE) of this part does not match the one (1k) provided in your BOM. Please confirm; | C11702 | https://jlcpcb.com/partdetail/12256-0402WGF1001TCE/C11702 | Basic | 20 | 20 JLCPCB | 0.02
U1 |  | STM32F405VGTx | LQFP-100_14x14mm_P0.5mm |  | Select by Customer | STM32F405VGT6 | STMicroelectronics | LQFP-100(14x14) | -40℃~+85℃ 1.8V~3.6V 12bit 12bit 168MHz 192KB 1MB 32 Bit 82 ARM Cortex-M4 Built-in FLASH LQFP-100(14x14) Microcontrollers (MCU/MPU/SOC) ROHS | Microcontrollers (MCU/MPU/SOC) |  | C56621 | https://jlcpcb.com/partdetail/STMicroelectronics-STM32F405VGT6/C56621 | Extended | 3 | 3 JLCPCB | 20.469
 | U2 | W25Q128JVS | SOIC-8_5.3x5.3mm_P1.27mm |  | Select by Customer | W25Q128JVSIQ | Winbond Elec | SOIC-8-208mil | -40℃~+85℃ 100,000 cycles 120ms@(32KB) 128Mbit 133MHz 1uA 2.7V~3.6V 20 Years 3ms SPI SOIC-8-208mil NOR FLASH ROHS | NOR FLASH | 1.The comment (W25Q128JVSIQ) of this part does not match the one (W25Q128JVS) provided in your BOM. Please confirm; | C97521 | https://jlcpcb.com/partdetail/WinbondElec-W25Q128JVSIQ/C97521 | Basic | 3 | 3 JLCPCB | 5.6652
U3 |  | ADXL375BCCZ | LGA_CC-14-1_ADI-L |  | Select by Customer | ADXL375BCCZ-RL7 | Analog Devices | LGA-14(3x5) | -40℃~+85℃ 100nA 16bit 2V~3.6V Accelerometer SPI、I2C X,Y,Z ±200g LGA-14(3x5) Accelerometers ROHS | Accelerometers | 1.The comment (ADXL375BCCZ-RL7) of this part does not match the one (ADXL375BCCZ) provided in your BOM. Please confirm; | C481898 | https://jlcpcb.com/partdetail/AnalogDevices-ADXL375BCCZRL7/C481898 | Extended | 3 | 3 JLCPCB | 28.8852
U4 |  | BMP390 | 10LGA_2X2X0p75_BOS-M |  | Select by Customer | BMP388 | Bosch Sensortec | LGA-10(2x2) | -40℃~+85℃ 1.65V~3.6V 1pa/K 2uA 30Kpa~1.25bar 50pa 8pa I2C、SPI LGA-10(2x2) Pressure Sensors ROHS | Pressure Sensors | 1.The comment (BMP388) of this part does not match the one (BMP390) provided in your BOM. Please confirm; | C779278 | https://jlcpcb.com/partdetail/BoschSensortec-BMP388/C779278 | Extended | 3 | 3 JLCPCB | 8.8614
 | U5 | BMI088 | Bosch_LGA-16_4.5x3mm_P0.5mm_LayoutBorder7x1y_ClockwisePinNumbering |  | Select by System | BMI088 | Bosch Sensortec | LGA-16(3x4.5) | -40℃~+85℃ Accelerometer Gyroscope LGA-16(3x4.5) Accelerometers ROHS | Accelerometers |  | C194919 | https://jlcpcb.com/partdetail/BoschSensortec-BMI088/C194919 | Extended | 3 | 3 JLCPCB | 28.8279
Y1 |  | FA-23816Mhz | Crystal_SMD_SeikoEpson_FA238-4Pin_3.2x2.5mm |  | Select by Customer | X1E0000210119 | Seiko Epson | SMD3225-4P | -40℃~+85℃ 12pF 16MHz 60Ω Crystal Oscillator ±10ppm ±20ppm SMD3225-4P Crystals ROHS | Crystals |  | C89371 | https://jlcpcb.com/partdetail/SeikoEpson-X1E0000210119/C89371 | Extended | 5 | 5 JLCPCB | 1.1835
J1,J6 |  | Conn_01x04 | PinHeader_1x04_P2.54mm_Vertical |  | No matches | No Part Selected
J3 |  | Conn_01x02 | PinHeader_1x02_P2.54mm_Vertical |  | No matches | No Part Selected
J7 |  | Screw_Terminal_01x02 | TerminalBlock_Phoenix_PT-1,5-2-3.5-H_1x02_P3.50mm_Horizontal |  | No matches | No Part Selected
SW1 |  | SW_Push | SW_PUSH_6mm_H4.3mm |  | No matches | No Part Selected
SW2,SW3 |  | SW_Push_Shielded | SW_Push_1P1T-SH_NO_CK_KMR2xxG |  | No matches | No Part Selected

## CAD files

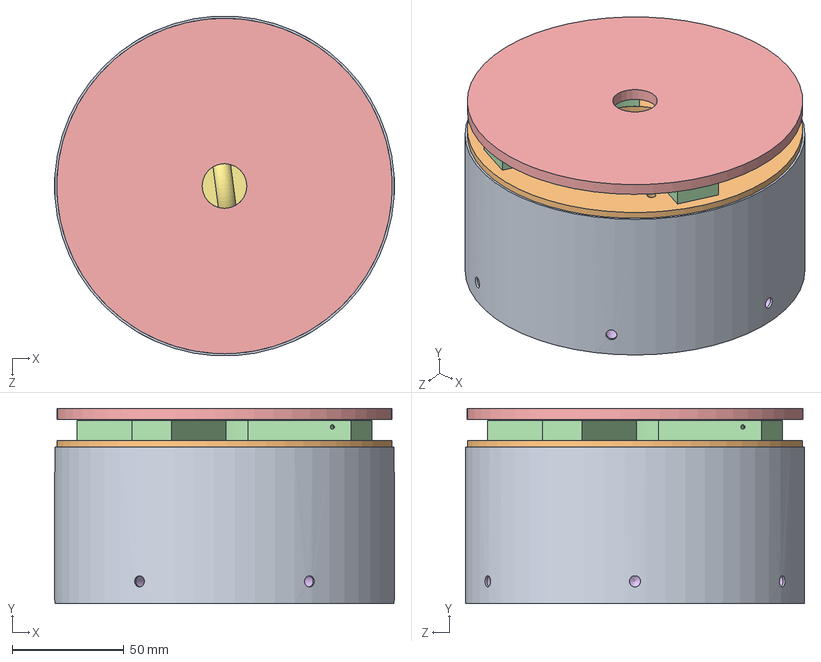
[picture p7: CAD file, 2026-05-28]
hardware/avionic_bay/ISP32/Deploy system v1.1/deploy system/complete deploy system v1.1.SLDASM
152.0 x 87.4 x 151.7 mm
connect
eject bottom plate
chamber lid x 4
black powder chamber x 4
separater plate
bottom
screw

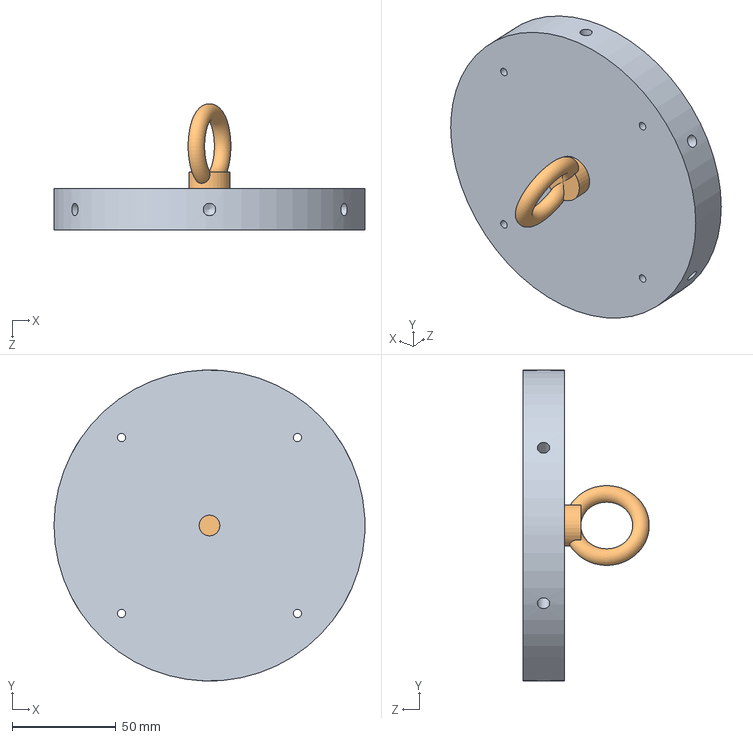
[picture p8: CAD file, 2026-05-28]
hardware/avionic_bay/ISP32/Deploy system v1.1/deploy system/底座/complete bottom.SLDASM
150.0 x 150.0 x 61.0 mm
bottom
screw

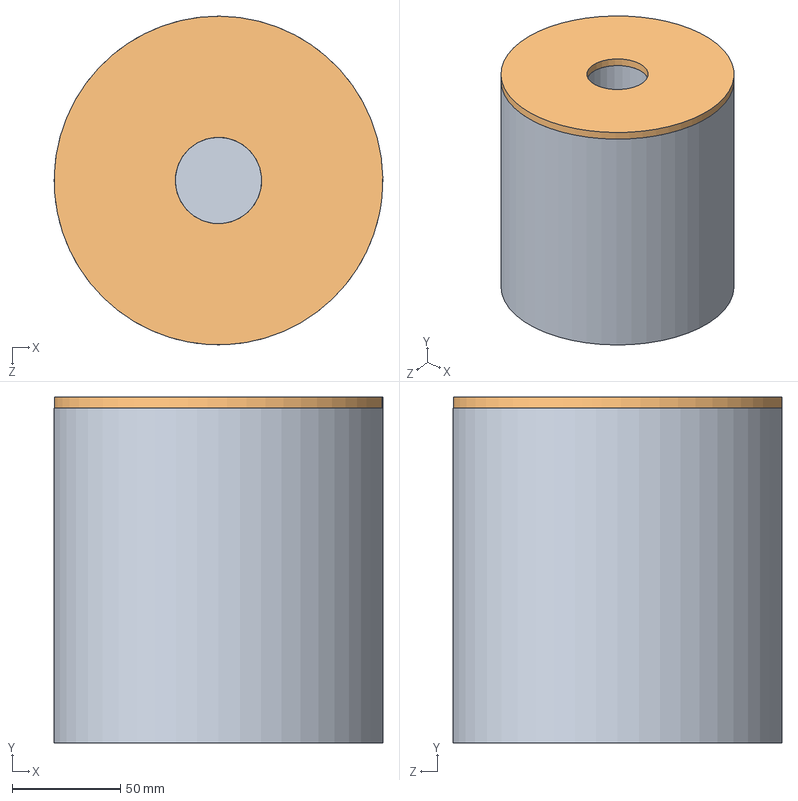
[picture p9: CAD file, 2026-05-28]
hardware/avionic_bay/ISP32/Deploy system v1.1/avionics bay/avionics bay.SLDASM
152.0 x 160.0 x 152.0 mm
avionics bay base
avionics bay lid

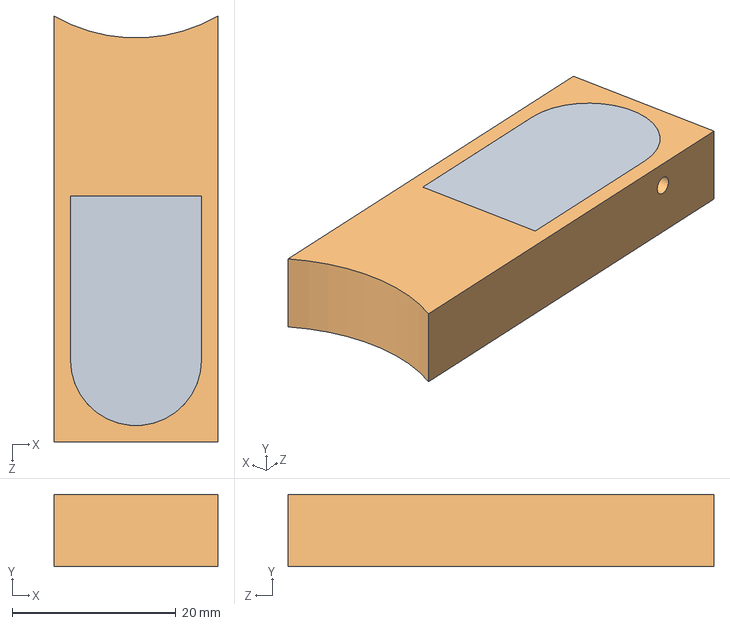
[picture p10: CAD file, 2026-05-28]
hardware/avionic_bay/ISP32/Deploy system v1.1/deploy system/火藥盤/complete chamber.SLDASM
20.0 x 8.80 x 52.0 mm
chamber lid
black powder chamber

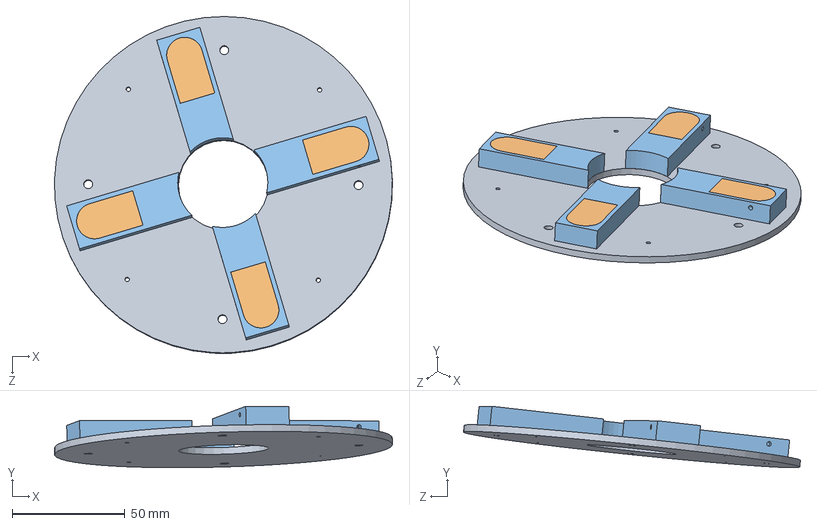
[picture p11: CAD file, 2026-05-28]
hardware/avionic_bay/ISP32/Deploy system v1.1/deploy system/火藥盤/complete eject plete.SLDASM
150.0 x 27.3 x 149.5 mm
eject bottom plate
chamber lid x 4
black powder chamber x 4

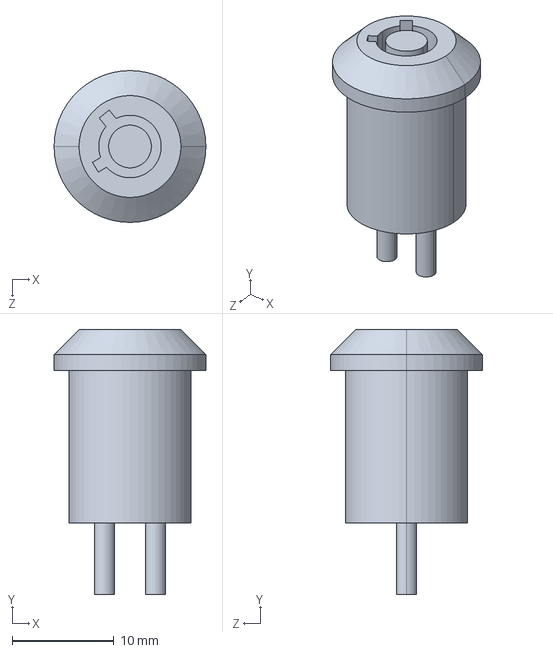
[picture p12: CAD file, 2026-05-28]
hardware/avionic_bay/ISP32/Deploy system v1.1/avionics bay/seperated/main switch.step.STEP
14.9 x 26.0 x 14.9 mm

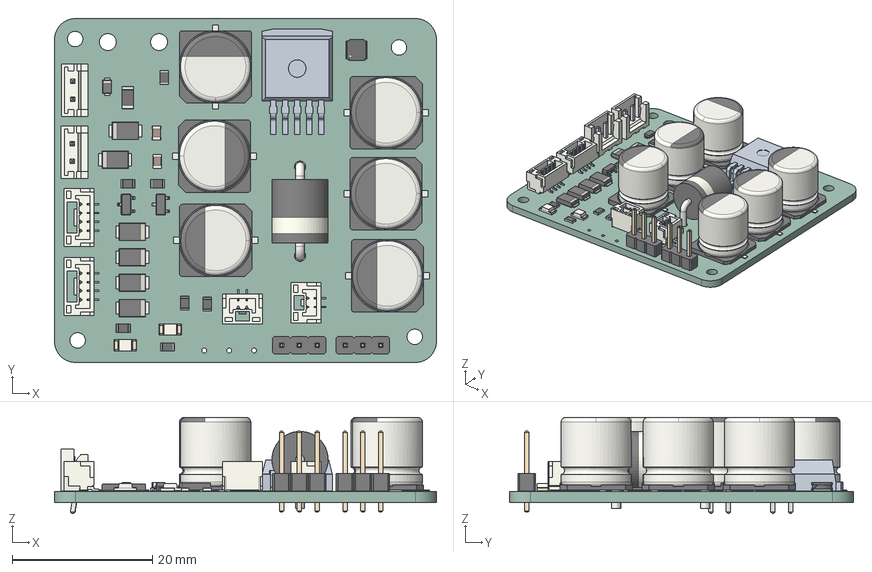
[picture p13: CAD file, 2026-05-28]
Deployment board/.step
54.5 x 49.0 x 13.7 mm
D_SOD-128 x 6
R_0805_2012Metric x 7
JST_EH_B2B-EH-A_1x02_P2.50mm_Vertical x 2
PinHeader_1x03_P2.54mm_Vertical x 2
CP_Elec_10x10.5 x 6
SOT-23 x 2
D_TUMD2
JST_GH_BM04B-GHS-TBT_1x04-1MP_P1.25mm_Vertical x 2
Fuse_1206_3216Metric
JST_GH_BM02B-GHS-TBT_1x02-1MP_P1.25mm_Vertical x 2
C_0805_2012Metric x 2
.step 1.23.1
L_Wurth_WE-LQSH-3012
LED_1206_3216Metric x 2
D_5KPW_P12.70mm_Horizontal
Deployment board_PCB

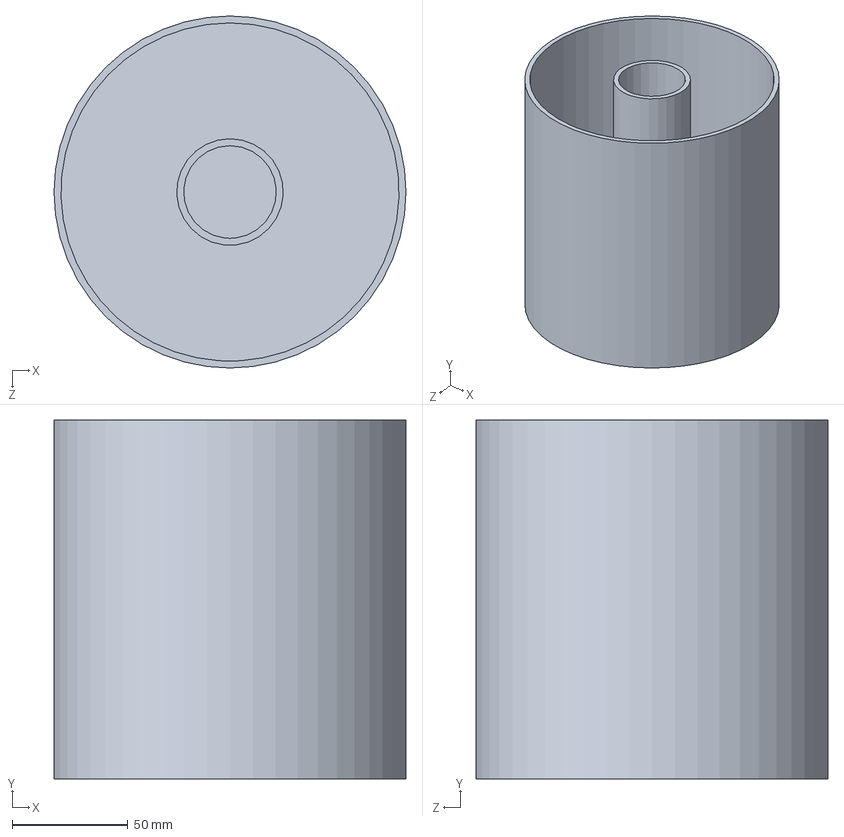
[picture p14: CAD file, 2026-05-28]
hardware/avionic_bay/ISP32/Deploy system v1.1/avionics bay/avionics bay base.SLDPRT
152.0 x 155.0 x 152.0 mm

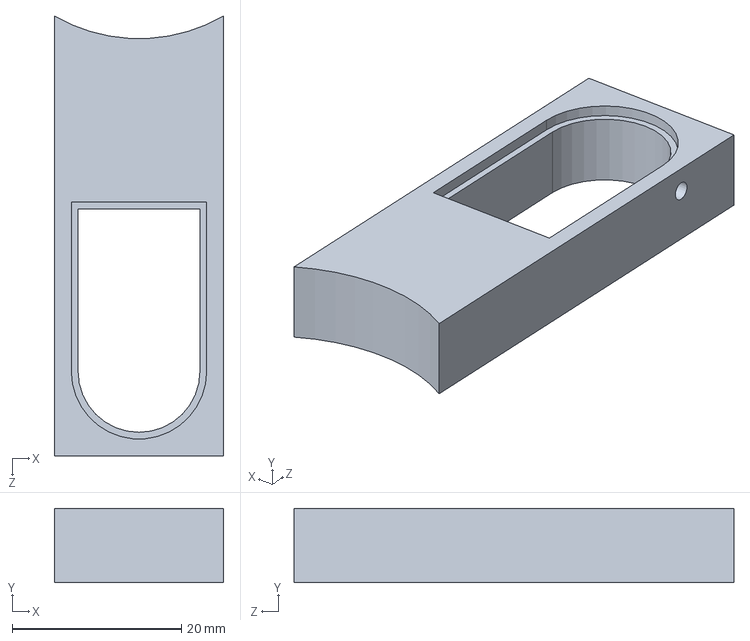
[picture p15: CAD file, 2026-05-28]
hardware/avionic_bay/ISP32/Deploy system v1.1/deploy system/火藥盤/black powder chamber.SLDPRT
20.0 x 8.80 x 52.0 mm

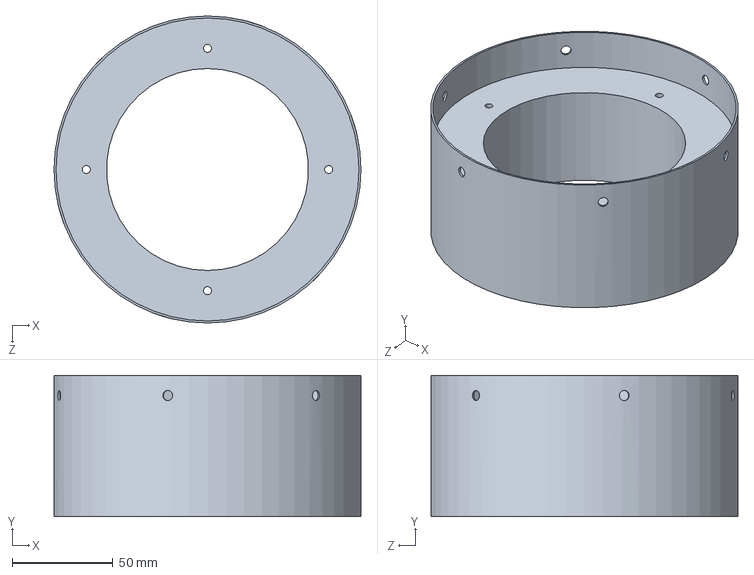
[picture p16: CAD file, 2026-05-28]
hardware/avionic_bay/ISP32/Deploy system v1.1/deploy system/連接/connect.SLDPRT
152.0 x 70.0 x 152.0 mm

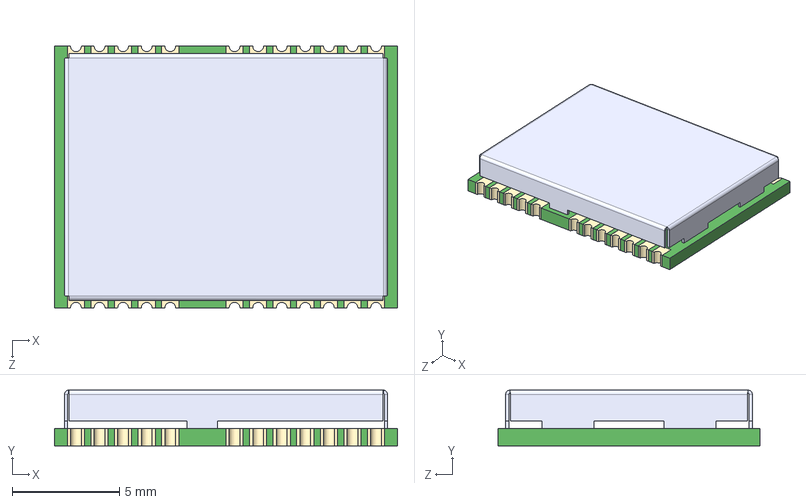
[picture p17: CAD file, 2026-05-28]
hardware/avionic_bay/ISP32/NEO-7M-0.STEP
16.0 x 2.60 x 12.2 mm

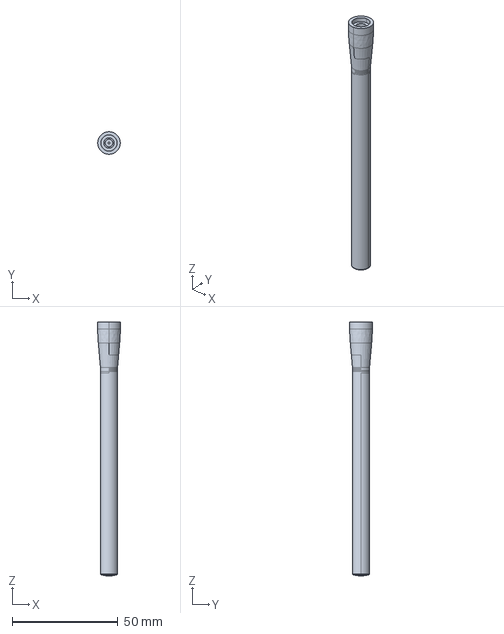
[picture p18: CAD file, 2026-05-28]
hardware/avionic_bay/pcb/c-ant-433-cw-hw-sma-a-3d.stp
10.7 x 10.7 x 120.0 mm

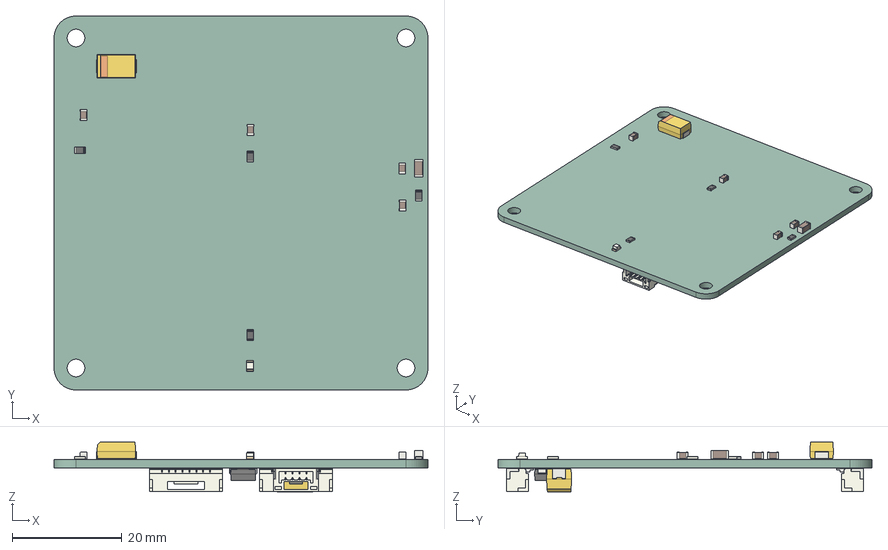
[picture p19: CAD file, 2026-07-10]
hardware/big_avionic/lora/lora.step
68.0 x 68.0 x 9.08 mm
CP_EIA-7343-31_Kemet-D
C_0805_2012Metric x 4
R_0805_2012Metric x 4
LED_0805_2012Metric
C_1206_3216Metric
CP_EIA-7343-43_Kemet-X
JST_GH_SM04B-GHS-TB_1x04-1MP_P1.25mm_Horizontal
JST_GH_SM08B-GHS-TB_1x08-1MP_P1.25mm_Horizontal x 2
D_SMA
lora_PCB

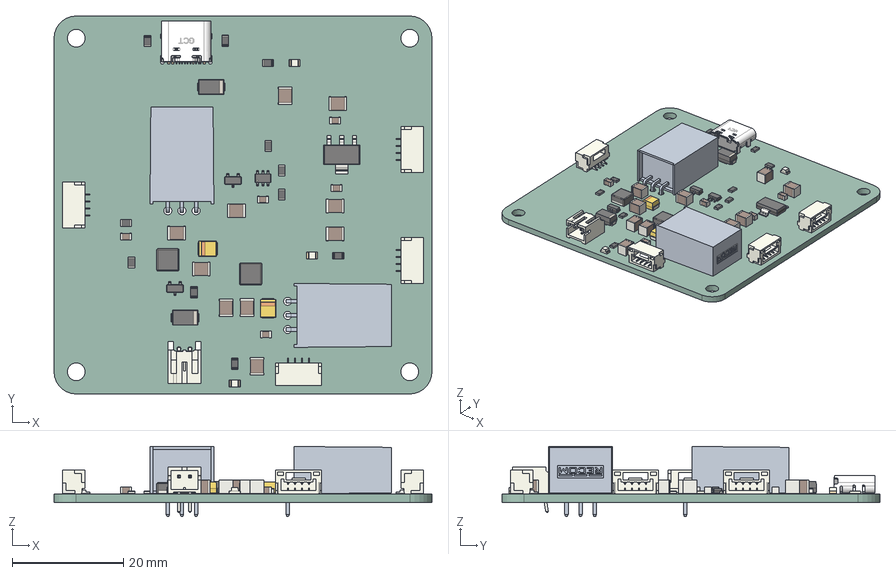
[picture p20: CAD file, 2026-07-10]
hardware/big_avionic/power layer_new/power layer.step
68.0 x 68.0 x 12.6 mm
LED_0805_2012Metric x 3
L_APV_ANR4020 x 2
R_0805_2012Metric x 11
D_SMA x 2
C_1210_3225Metric x 10
CP_EIA-3528-21_Kemet-B x 2
TSOT-23-6
power layer 1.10.1 x 2
C_0805_2012Metric x 5
JST_GH_SM04B-GHS-TB_1x04-1MP_P1.25mm_Horizontal x 4
SOT-23 x 2
HSG_Ĭɏ
JST_PH_S2B-PH-K_1x02_P2.00mm_Horizontal
SOT-223
power layer_PCB

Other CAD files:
hardware/avionic_bay/ISP32/Deploy system v1.1/avionics bay/seperated/R_0603_1608Metric.step.STEP
hardware/big_avionic/top_layer/top_layer.step
hardware/avionic_bay/CAD/GPS_v1.SLDPRT
hardware/avionic_bay/CAD/Battery_v1.3mf
hardware/avionic_bay/CAD/Battery_v1.SLDPRT
hardware/avionic_bay/CAD/Battery_v1.STL
hardware/avionic_bay/CAD/GPS_v1.STL
hardware/avionic_bay/CAD/body.SLDPRT
hardware/avionic_bay/CAD/body_v0.3MF
hardware/avionic_bay/CAD/body_v0.SLDPRT
hardware/avionic_bay/CAD/body_v1.SLDPRT
hardware/avionic_bay/CAD/body_v10.SLDPRT
hardware/avionic_bay/CAD/body_v1_test.SLDPRT
hardware/avionic_bay/CAD/body_v2.3mf
hardware/avionic_bay/CAD/body_v2.SLDPRT
hardware/avionic_bay/CAD/body_v3.SLDPRT
hardware/avionic_bay/CAD/body_v4.SLDPRT
hardware/avionic_bay/CAD/body_v5.SLDPRT
hardware/avionic_bay/CAD/body_v6.SLDPRT
hardware/avionic_bay/CAD/body_v6.STL
hardware/avionic_bay/CAD/body_v7.3mf
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

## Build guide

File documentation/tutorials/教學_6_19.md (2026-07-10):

# RocketCom 航電系統與 C/C++ 飛控軟體開發教學 (6/19)

歡迎來到 RocketCom 航電主控系統的開發與學習環境！本教學旨在帶領讀者深入理解火箭飛控系統的底層軟韌體設計。我們將結合專案真實代碼，從系統架構、C/C++ 語法特徵、各感測器驅動與 EKF 演算法，一直到編譯工具鏈與開發環境進行全方位的剖析。

為了讓讀者能夠達到「從完全不會到可以手動修改目前代碼」的程度，我們除了本教學文件外，更設計了 **`教學_6_19.html`** 單一網頁應用程式。雙擊該檔案即可打開一個完整的**「互動式學習中心」**，內含大廳、語法字典、三大硬體模擬器（狀態機/位元運算/任務排程），以及全專案 32 個原始碼與標頭檔的**「互動式逐行對照瀏覽器」**。

---

## 1. 系統整體架構 (System Architecture)

航電系統的設計核心是**高頻採樣、即時估算、安全開傘與非同步儲存**。我們基於 STM32F407 晶片，並運行 FreeRTOS 即時作業系統。

```
[硬體定時器中斷 (TIM3, TIM6, TIM7)] ----(Ping-Pong 雙緩衝區)----> [defaultTask (1 kHz 主任務)]
                                                                        |
                                                           (非阻塞佇列 xEKFQueue)
                                                                        v
[DataLogging_Task (低優先級)] <----(雙快取/FatFs)---- [EKF_Task (高優先級，CCM RAM)]
```

### 1.1 FreeRTOS 任務排程與多任務設計
系統內劃分了多個不同優先級的任務，以保證關鍵控制迴圈的即時性：
* **`defaultTask` (1 kHz 週期，優先級 `osPriorityNormal`)**：主控制任務，運行於 1ms 週期。負責將定時中斷收集到的高頻感測器資料進行**降採樣濾波**與**時間對齊**，重構出 1000 Hz 的同步資料包。當積累滿 100 筆資料（即 100ms 份）時，將其包裝並透過訊息佇列（message queue）非阻塞地發送給 EKF 任務。此外，該任務也負責以 100 Hz (10ms) 頻率步進飛行狀態機（FSM）、處理 GPS 序列埠資料流、電池電壓 ADC 採樣與 LED 狀態指示。
* **`ekfTask` (10 Hz 週期，優先級 `osPriorityHigh`)**：高優先級 EKF 估算任務。平時處於阻塞狀態，一旦從 `xEKFQueue` 接收到一組 100ms 的資料包指標，便立即喚醒，在背景以 1000 Hz 的推進步長對該 100 筆資料進行回放（Playback），完成預測與量測更新，並輸出最新的姿態與高度估算。
* **`diagTask` (優先級 `osPriorityLow`)**：低優先級診斷任務。負責在地面調試階段透過序列埠輸出感測器自檢狀態，或接收終端指令。
* **`loraTxTask` (優先級 `osPriorityLow`)**：下行遙測傳送任務。以 10Hz~20Hz 頻率將當前的飛控狀態與感測器資料打包，並驅動 LoRa 無線模組送出。

### 1.2 中斷處理 (Interrupts) 與 NVIC 優先級設定
航電系統嚴禁在任務層級以阻塞式輪詢（Polling）方式讀取感測器，否則會極大地消耗 CPU 時間並引入不確定的抖動。因此，我們使用硬體定時器中斷來精確控制採樣時間：
* **TIM3 (3.2 kHz)**：每 $312.5\ \mu\text{s}$ 觸發一次，讀取高 G 加速度計 ADXL375。
* **TIM6 (1.6 kHz)**：每 $625\ \mu\text{s}$ 觸發一次，讀取 BMI088 加速度計。
* **TIM7 (2.0 kHz)**：每 $500\ \mu\text{s}$ 觸發一次，讀取 BMI088 陀螺儀。
* **USART6 (GPS)** 與 **USART2 (板間鏈路)**：配置 DMA 循環接收加上**空閒中斷 (IDLE)**，使得當資料流中斷（一幀結束）時，立即觸發中斷服務程式進行背景解析，完全避免任務主動查詢。

### 1.3 FreeRTOS 系統呼叫限制與中斷防護
在 Cortex-M 架構中，中斷優先級數值越小，物理優先級越高。
* 系統設定 `configLIBRARY_MAX_SYSCALL_INTERRUPT_PRIORITY = 5`，這意味著優先級為 **0 到 4** 的中斷具有極高的即時性，不受 FreeRTOS 核心干預，但也**絕不能呼叫任何 FreeRTOS 的 API**（例如 `xQueueSendFromISR`），否則會導致核心狀態損毀。
* 優先級為 **5 到 15** 的中斷則可以安全地呼叫 `*FromISR` 結尾 of 的 API。
* 在本專案中：
  - 各採樣定時器（TIM3, TIM6, TIM7）的 NVIC 優先級被配置為 **6**，處於安全臨界區以下，既保證了極高的中斷響應速度，又保留了必要時與 RTOS 互動的能力（儘管驅動內部出於極致性能考量，刻意避免了任何核心呼叫）。
  - USB 中斷（OTG_FS_IRQn）配置為 **4**，由於其高於 syscall 限制，該中斷服務函式內部被嚴格禁止呼叫任何 RTOS 機制。

### 1.4 避免資料撕裂的 Ping-Pong 雙緩衝機制 (Double Buffering)
高頻中斷在背景寫入緩衝區，而 `defaultTask` 在前景讀取資料。若兩者同時存取同一個記憶體區塊，會導致正在讀取的 3D 加速度計讀到「前 2 軸是新資料，第 3 軸是舊資料」的資料撕裂（Data Tearing）現象。
為了解決這個問題，系統設計了 **Ping-Pong 雙緩衝機制**。以 ADXL375 為例：
```c
static volatile float g_adxl_batches[2][32][3]; // 雙緩衝二維陣列
static volatile uint8_t g_adxl_active_batch = 0; // 當前中斷寫入的緩衝區索引
static volatile uint16_t g_adxl_sample_cnt = 0;
```
* **中斷寫入端**：TIM3 中斷將資料寫入 `g_adxl_batches[g_adxl_active_batch][g_adxl_sample_cnt]`。當 `g_adxl_sample_cnt` 達到 32 筆時，中斷服務程式會執行：
  ```c
  g_adxl_active_batch = !g_adxl_active_batch; // 切換至另一個緩衝區
  g_adxl_sample_cnt = 0;
  g_adxl_ready_batch_idx = !g_adxl_active_batch; // 標記已填滿的緩衝區索引
  g_adxl_new_batch_ready = 1; // 設置就緒旗標
  ```
* **任務讀取端**：`defaultTask` 檢測到 `g_adxl_new_batch_ready == 1` 時，清除旗標，並直接讀取穩定且不再被中斷修改的 `g_adxl_batches[g_adxl_ready_batch_idx]` 資料進行降採樣，整個過程無鎖且無衝突。

### 1.5 CCM RAM 核心耦合記憶體優化
STM32F407 晶片除了常規的 112KB SRAM1/SRAM2 外，還具備一塊獨立的 **64KB CCM RAM (Core-Coupled Memory)**。
* **物理特性**：CCM RAM 直接連接至 Cortex-M4 的 D-bus（資料匯流排），與 CPU 核心同頻且具備零等待週期（Zero Wait-State）的高速存取特性。然而，它**不連接至 AHB 匯流排矩陣**，這意味著所有 DMA 週邊（如 SDIO、USART、SPI DMA）都**無法**讀取或寫入 CCM RAM。
* **優化配置**：我們將運算密集度極高、且不涉及週邊 DMA 傳輸的 **EKF 狀態變數 (`EKF_x`、`EKF_P`、`EKF_q`)**、**EKF 任務控制塊 (`StaticTask_t EKF_TaskControlBlock`)** 及 **`EKF_TaskStack` 堆疊空間**，透過 `CCMRAM` 巨集強行指定編譯至 `.ccmram` 記憶體區段：
  ```c
  #define CCMRAM __attribute__((section(".ccmram")))
  static float EKF_x[6] CCMRAM;
  ```
  這樣做既榨乾了 CPU 的計算潛能，又將常規 SRAM 釋放給了需要頻繁 DMA 寫入的 SD 卡（FatFs）和序列埠通訊，實現了最佳系統資源配置。

---

## 2. C/C++ 語法核心與暫存器操作 (C/C++ Language Core)

在深入分析原始碼之前，我們先複習嵌入式 C 語言中最核心的語法機制。

### 2.1 指標 (Pointers) 與記憶體位址
指標是存放記憶體位址的變數。在驅動中，我們常用指標來傳遞複雜的資料結構或控制硬體週邊。例如：
```c
HAL_StatusTypeDef ADXL375_Init(SPI_HandleTypeDef *hspi);
```
這裡 `hspi` 是一個指向 `SPI_HandleTypeDef` 結構體的指標。在函式內部，我們使用 `->` 運算子（成員存取指標運算子）來存取該結構體的成員：
```c
hspi->Instance->DR = val; // 往 SPI 資料暫存器寫入值
```
使用指標傳遞結構體的好處是**避免了記憶體複製的開銷**（只需傳遞一個 32 位元的位址），且能直接修改指標指向的實際資料。

### 2.2 結構體 (Structs) 與記憶體對齊 (`__attribute__((packed))`)
預設情況下，32 位元編譯器會為了對齊效率而在結構體成員之間插入填充空間（Padding）。例如：
```c
struct StandardStruct {
    uint8_t a;  // 1 byte
    uint32_t b; // 4 bytes (前面會被補 3 bytes 使得位址是 4 的倍數)
}; // 佔用 8 bytes
```
然而，在設計**下行遙測封包**或**板間通訊協定**時，我們的二進位資料必須是緊湊的，容不得任何空白填充。為此，我們使用 `__attribute__((packed))` 屬性告訴編譯器「取消對齊填充」：
```c
typedef struct __attribute__((packed)) {
    uint8_t  sync0;   // Offset 0
    uint8_t  sync1;   // Offset 1
    uint8_t  seq;     // Offset 2
    uint8_t  state;   // Offset 3
    uint32_t tick_ms; // Offset 4
} LinkPacket_t; // 緊湊排列，不含任何填充位元組
```

### 2.3 暫存器按位操作：位移 (`<<`)、按位與 (`&`) 與按位或 (`|`)
在硬體驅動中，我們需要頻繁地讀取和修改感測器的暫存器。
1. **拼接暫存器高低字節**：感測器的 16 位元數據通常拆成兩個 8 位元暫存器（如 `data_L` 和 `data_H`）。拼接方法如下：
   ```c
   int16_t raw_val = (int16_t)((rx_buf[1] << 8) | rx_buf[0]);
   ```
   * `rx_buf[1] << 8`：將高位位元組向左移動 8 位元，移到高 8 位。
   * `| rx_buf[0]`：透過按位或（OR）運算，將低位位元組填入低 8 位，拼成一個 16 位元整數。
2. **清除與置位特定位元**：
   * **置位 (Set bit)**：`reg_val |= (1 << 3);` —— 將暫存器的第 3 位置為 1，其餘位元保持不變。
   * **清除 (Clear bit)**：`reg_val &= ~(1 << 3);` —— 將暫存器的第 3 位清除為 0，其餘位元保持不變。

---

## 3. 飛控底層與核心原始碼模組解析 (Custom Code Overview)

以下是全專案 12 個核心模組的結構解說。讀者可以雙擊並打開 **`教學_6_19.html`**，切換到 **「🔍 原始碼逐行解析」** 標籤，然後使用下拉選單選擇對應的 `.c` 或 `.h` 檔案，即可在網頁中查看每一行程式碼的詳細說明與語法解鎖：

1.  **I2C 軟體總線 (`soft_i2c.h` / `soft_i2c.c`)**：利用普通 GPIO 模擬 I2C 時序讀寫 MMC5983MA。
2.  **高 G 加速度計驅動 (`adxl375.h` / `adxl375.c`)**：設定 ADXL375 的 3.2kHz SPI 數據讀取與 $49\text{mg}$ 解析度運算。
3.  **高性能 IMU 驅動 (`bmi088.h` / `bmi088.c`)**：讀取高精度的低 G 加速度與陀螺儀角速度。
4.  **氣壓高度計驅動 (`bmp388.h` / `bmp388.c`)**：調用官方 Bosch BMP3 API 進行溫度與氣壓浮點補償解算。
5.  **地磁計與校準 (`mmc5983.h` / `mmc5983.c`)**：包含 SET/RESET 固定脈衝，消去環境干擾與硬體磁滯。
6.  **GPS 解析核心 (`gps.h` / `gps_parse.h` / `gps.c`)**：USART6 DMA 循環加空閒中斷背景接收，實現 NMEA 語句校驗與經緯度實時換算。
7.  **姿態高度融合 EKF (`ekf.h` / `ekf_guard.h` / `attitude_math.h` / `ekf.c`)**：高優先級 1kHz EKF 導航演算法，運行於 CCM RAM，利用氣壓高度和重力校正四元數姿態。
8.  **有限狀態機 (`fsm.h` / `fsm.c`)**：狀態機更新邏輯，判斷發射、滑行、頂點、下落並控制雙踢火火工品。
9.  **下行遙測打包 (`telemetry.h` / `telemetry.c`)**：利用緊湊結構體包裝飛行狀態與感測器數據。
10. **多板冗餘備用鏈路 (`link.h` / `link_hw.h` / `link_proto.h` / `link.c` / `link_hw.c` / `link_proto.c`)**：USART2 板間通信與備用點火仲裁（BackupGate）。
11. **Flash 環形儲存 (`w25qxx.h` / `flash_ring_math.h` / `w25qxx.c`)**：W25Q256 的 SPI 物理讀寫與日誌環形指針管理。
12. **系統入口與主調度 (`main.h` / `main.c`)**：FreeRTOS 核心調度起點、TIM 中斷 Ping-Pong 緩衝配置與看門狗餵狗。

---

## 4. 之後如何修改代碼 (Code Modification Guide)

### 4.1 如何新增感測器
1.  **引腳配置**：在 STM32CubeMX 中設定 CS 或 I2C 引腳，生成代碼。
2.  **驅動編寫**：參考 `adxl375.c`，編寫感測器初始化與物理值讀取。
3.  **高頻中斷採樣**：將讀取動作加入定時器中斷（如 TIM6），寫入 Ping-Pong 寫入端。
4.  **前景對齊讀取**：在 `main.c` 的主任務中，檢查就緒標誌，讀取降採樣資料並封裝。

### 4.2 修改開傘參數
1.  打開 `Main_Code/Core/Inc/fsm.h`。
2.  修改起飛加速度巨集 `LIFTOFF_ACCEL_THRESHOLD` 或主傘高度巨集 `TARGET_MAIN_ALTITUDE`。
3.  在 `fsm.c` 的 `FSM_Step()` 中調整轉移規則。

---

## 5. 編譯、Make 與開發環境 (Toolchain & Build Configurations)

### 5.1 編譯四步驟
1.  **預處理**：處理巨集替換與標頭檔展開，生成 `.i`。
2.  **編譯**：將 C 代碼優化並翻譯成組合語言，生成 `.s`。
3.  **彙編**：將組合語言翻譯成二進位機器碼，生成物件檔案 `.o`。
4.  **連結**：根據 `.ld` 連結腳本，分配變數與程式碼實體位址，輸出 `.elf` 與 `.bin`。

### 5.2 Make 與 Makefile
Make 工具藉由讀取 Makefile 規則，實現增量編譯（只編譯修改過的文件），大幅提高開發效率。

### 5.3 CubeIDE 路徑配置
手動新增原始碼後，必須在屬性中配置 C/C++ General -> Paths and Symbols，將標頭檔目錄加入 Include Paths，將 `.c` 目錄加入 Source Location，否則會出現找不到檔案的編譯或連結錯誤。

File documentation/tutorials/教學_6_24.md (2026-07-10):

# RocketCom 航電系統開發教學（6/24 完整版）

> 本檔是 `教學_6_19.md` 的後續完整版。除沿用 6/19 的系統架構與 C/C++ 基礎外，
> 補齊 6/19 之後新增的三大子系統：**三角色編譯架構（主/備/地面站）**、
> **板間鏈路與不對稱備援**、**雙鏈路二進制遙測協定**、**地面站接收器**，
> 以及**主機端純邏輯測試體系**與 **Python 工具鏈**。
>
> 文件純 Markdown、自成一體。需要逐行對照原始碼時，仍可開啟 `教學_6_19.html`
> 的「互動式逐行瀏覽器」（涵蓋當時 32 個檔），本檔則補上新模組的講解。
>
> 本檔遵循專案 `docs/AI_output_requirement.md`：不使用 emoji、不截斷重要輸出，
> 以 `[OK]` / `[WARN]` / `[ERROR]` 文字標籤取代圖示，確保序列埠相容性。

---

## 目錄

1. 系統總覽與三角色架構
2. 即時架構（FreeRTOS / 中斷 / 雙緩衝 / CCM RAM）
3. C/C++ 語法核心
4. 感測與狀態估算（感測器 / 軸向 / EKF / 健康降級）
5. 板間鏈路與不對稱備援
6. 雙鏈路二進制遙測協定
7. 地面站 ROLE_GROUND
8. 主機端純邏輯測試體系
9. Python 工具鏈
10. 如何修改代碼
11. 編譯與工具鏈

---

## 1. 系統總覽與三角色架構

RocketCom 的核心特性是 **「同一份 firmware、用編譯期角色切出三個 binary」**。
這讓主航電、備援航電、地面站共用感測器驅動、EKF、協定與測試，維護單一真相來源。

角色定義集中於 `Main_Code/Core/Inc/board_config.h`（純常數巨集，不依賴 HAL／RTOS，
故純邏輯模組與 host 測試也能 include）：

```c
#define ROLE_PRIMARY 0   /* 主航電：完整飛控 + GPS/磁力計/LoRa 發送 + 板間鏈路 */
#define ROLE_BACKUP  1   /* 備援航電：只跑 MCU-layer 飛控（IMU/baro/highG→EKF→FSM→點火）*/
#define ROLE_GROUND  2   /* 地面站：只「接收」LoRa 下行 + 自身 GPS → SD/Flash/USB-CDC */

#ifndef BOARD_ROLE
#define BOARD_ROLE   ROLE_PRIMARY   /* MAKE_ROLE_LINE：build-backup/build-ground 改此行 */
#endif
```

### 1.1 功能閘（Feature Gates）

`main.c` 用 `#if FEATURE_*` 把對應驅動的 init／task 包起來，編譯期決定哪些子系統存在，
**關閉的功能完全不佔 code/RAM/CPU**：

| 功能巨集 | 主航電 | 備援 | 地面站 | 說明 |
|---|:---:|:---:|:---:|---|
| `FEATURE_GPS` | 是 | 否 | 是 | NEO-M9N GPS（USART6） |
| `FEATURE_MAG` | 是 | 否 | 否 | MMC5983MA 磁力計（軟體 I2C） |
| `FEATURE_LORA_TX` | 是 | 否 | 否 | 下行遙測「發送」 |
| `FEATURE_LORA_RX` | 否 | 否 | 是 | 下行遙測「接收」 |
| `FEATURE_FLIGHT` | 是 | 是 | 否 | 飛控管線（EKF/FSM/點火） |
| `FEATURE_LINK` | 是 | 是 | 否 | USART2 板間鏈路 |
| `FEATURE_USB_CDC` | 否 | 否 | 是 | USB 虛擬序列埠串流給 PC |

設計上要留意的一個工程取捨：**W25Q128 Flash 與 E80 920MHz LoRa 共用 SPI3**。
因此即使備援／地面站不發遙測，SPI3 周邊本身不能關（它們仍要寫 Flash）；備援是「不啟用
E80 驅動並按住其 RST 釋放匯流排」，地面站則「啟用 E80 但走 RX，讀 FIFO 與寫 Flash 以
SPI3 互斥鎖序列化」。這段邏輯詳見 `board_config.h` 的註解與 `w25qxx.c`。

### 1.2 一份程式碼、三個 binary 的建置

頂層 `Makefile` 提供：

```
make            # 主航電（ROLE_PRIMARY）
make build-backup   # 備援（ROLE_BACKUP），輸出 *_backup.elf
make build-ground   # 地面站（ROLE_GROUND），輸出 *_ground.elf
```

`build-backup` / `build-ground` 的手法很單純但要懂：先備份 `board_config.h`，用 `sed`
把標有 `MAKE_ROLE_LINE` 的那行改成對應角色，建置，**完成後一律還原** `board_config.h`，
再把產出的 `.elf` 另存為對應名稱。STM32CubeIDE 使用者則建議改用第二個 build
configuration（preprocessor 加 `BOARD_ROLE=ROLE_BACKUP`）。

---

## 2. 即時架構（FreeRTOS / 中斷 / 雙緩衝 / CCM RAM）

系統基於 STM32F407 + FreeRTOS。設計核心是**高頻採樣、即時估算、安全開傘、非同步儲存**。

### 2.1 任務與實測頻率（以源碼為準）

| 任務 | 頻率 | 優先級 | 職責 |
|---|---|---|---|
| `defaultTask` | **1 kHz**（`wake_tick += 1U`） | Normal | 主控迴圈：對齊高頻感測器、步進 FSM、處理 GPS/磁力計、餵狗、廣播板間鏈路 |
| `EKF_Task` | ~10 Hz 喚醒、內部 1 kHz 回放 | High（CCM RAM） | 每收到一批（~100 ms / 100 筆）就回放預測＋量測更新 |
| `LoRaTelemetry_Task` | **5 Hz**（`LORA_TELEM_PERIOD_MS=200`） | Low | 打包 79-byte 遙測，經 E22 / E80 發送 |
| `DiagnosticTask` | ~50 Hz（20 ms） | Low | 序列埠自檢、堆疊水位 0.2 Hz 印出 |

主迴圈內以「`tick % 週期 == 0`」分頻派工：

```c
if (tick % FSM_STEP_PERIOD_MS == 0) { ... }   /* FSM_STEP_PERIOD_MS = 10U → FSM 100 Hz */
if (tick % LINK_TX_PERIOD_MS == 0)  { ... }   /* LINK_TX_PERIOD_MS  = 50U → 板間鏈路 20 Hz */
```

所以一句話記住節律：**主迴圈 1 kHz、FSM 100 Hz、板間 20 Hz、下行遙測 5 Hz、EKF 批次回放**。

### 2.2 中斷與 NVIC 優先級

嚴禁在任務層級用阻塞輪詢讀感測器。改用硬體定時器中斷精準控時：

- **TIM3 (3.2 kHz)**：讀高 G 加速度計 ADXL375（SPI1）。
- **TIM6 (1.6 kHz)**：讀 BMI088 加速度計（SPI2）。
- **TIM7 (2.0 kHz)**：讀 BMI088 陀螺儀（SPI2）。
- **USART6（GPS）/ USART2（板間鏈路）**：DMA 循環 + 空閒中斷（IDLE），幀結束才觸發背景解析。
- BMP388 氣壓計則於**主迴圈 task context** 輪詢（~200 Hz），非高頻 ISR。

FreeRTOS 防護重點：`configLIBRARY_MAX_SYSCALL_INTERRUPT_PRIORITY = 5`。優先級數值
0～4 物理優先級最高、**絕不可呼叫任何 FreeRTOS API**；5～15 才能安全呼叫 `*FromISR`。
專案中採樣定時器 NVIC = 6（安全臨界區以下），USB 中斷 = 4（高於 syscall 限制，內部禁呼叫 RTOS）。

### 2.3 Ping-Pong 雙緩衝（避免資料撕裂）

高頻 ISR 在背景寫、`defaultTask` 在前景讀。若共用同一塊記憶體，會讀到「前兩軸新、第三軸舊」
的撕裂資料。解法是雙緩衝：ISR 寫 A、就緒後切到 B 並設旗標，任務只讀「已填滿且不再被改」
的那塊，全程無鎖。以 ADXL375 為例：

```c
static volatile float   g_adxl_batches[2][32][3]; /* 雙緩衝 */
static volatile uint8_t g_adxl_active_batch = 0;
/* ISR 滿 32 筆即： active = !active; cnt = 0; ready_idx = !active; new_ready = 1; */
```

### 2.4 CCM RAM 優化

F407 有一塊 64 KB **CCM RAM** 直連 Cortex-M4 D-bus、零等待，但 **DMA 無法存取**。
專案把運算密集且不需 DMA 的 **EKF 狀態（`EKF_x`/`EKF_P`/`EKF_q`）、EKF 任務 TCB 與堆疊**
以 `__attribute__((section(".ccmram")))` 放進 CCM，把常規 SRAM 留給需要 DMA 的 SD 卡與序列埠。

---

## 3. C/C++ 語法核心

### 3.1 指標
驅動常以指標傳遞硬體控制塊，避免複製、可直接改實體：
```c
HAL_StatusTypeDef ADXL375_Init(SPI_HandleTypeDef *hspi);
hspi->Instance->DR = val;   /* -> 為「成員存取指標運算子」 */
```

### 3.2 packed 結構（協定封包的根基）
預設編譯器會在成員間插入對齊填充。但遙測／板間封包必須緊湊、不容填充，故用
`__attribute__((packed))`。**本專案兩種封包（遙測、板間）都是 packed**：
```c
typedef struct __attribute__((packed)) {
    uint8_t  sync0; uint8_t sync1; uint8_t seq; uint8_t state;
    uint32_t tick_ms;   /* 緊接 state，無填充 */
} ExamplePacket_t;
```

### 3.3 位元運算
```c
int16_t raw = (int16_t)((rx[1] << 8) | rx[0]); /* 拼高低位元組 */
reg |=  (1 << 3);   /* 置位 */
reg &= ~(1 << 3);   /* 清位 */
```

---

## 4. 感測與狀態估算

### 4.1 感測器套件

| 感測器 | 介面 | 角色 | 備註 |
|---|---|---|---|
| BMI088（IMU 加速度＋陀螺） | SPI2 | 主姿態 | TIM6 1.6k / TIM7 2.0k |
| ADXL375（高 G ±200g） | SPI1 | 升空/頂點鑑別 | TIM3 3.2k；SPI1 與 BMP388 共線需互斥 |
| BMP388（氣壓高度） | SPI | 高度 + 開傘備援 | 主迴圈輪詢 ~200 Hz；發射台鎖定 T0 溫補 |
| MMC5983MA（磁力計） | **軟體 I2C** | 發射台航向鎖定 | 因硬體 I2C 易鎖死，2026-06-03 改 bitbang + 100 Hz polling |
| NEO-M9N（GPS） | USART6 | 水平位置 / 授時 | DMA-to-idle、NMEA-0183（GGA/RMC） |

### 4.2 軸向單一真相：`sensor_axis.h`

每顆感測器物理擺放方向不同，若各處臨時推正負號遲早出錯。專案把所有「感測器原生軸 → 機體
軸（X=右、Y=前、Z=上，右手系）」的對應集中在 `sensor_axis.h` 的 inline 函式，驅動層只輸出
原生軸、反向修正集中於此。`tests/test_sensor_axis.c` 以「旋轉矩陣行列式必為 +1」鎖定正確性。
**要改軸向，只動這個檔，並用測試驗證，不要手推。**

### 4.3 EKF 與健康降級

`ekf.c`（高優先級、CCM RAM）以四元數做姿態、氣壓做高度、GPS 做水平位置、磁力計在發射台做
航向鎖定。資料流：高頻 ISR 充填雙緩衝 → `defaultTask` 重構對齊成 1 kHz 同步包、滿批送
`xEKFQueue` → `EKF_Task` 回放預測＋量測更新 → 輸出姿態/高度供 FSM。

可靠度設計兩條：
- `ekf_guard.h`：回傳健康位，異常（四元數失常、發散等）即非 0。FSM 收到 EKF 不健康會**切換
  到 raw-baro 降級鏈**（純氣壓高度 + 加速度觸發，不靠 EKF 高度）。
- 垂直通道發散自救：偵測 DIVERGE 超過 3 s 自動重置。

> 工程備忘（尚未上板驗證）：`docs/設計_ADXL375_EKF融合與SPI1並發.md` 指出一個前置阻斷項——
> BMI088/ADXL375 樣本單位是 g，但 `EKF_Predict` 以 m/s² 扣重力積分，靜置由校準抵銷（故 bench
> 正常）但**動態被低估約 9.81×**。融合 ADXL 前須先把加速度統一為 SI（m/s²）。

---

## 5. 板間鏈路與不對稱備援

主航電與備援航電是**兩塊相同的 MCU 板**，各自獨立跑飛控；它們用 USART2 硬體全雙工互通狀態，
靠「不對稱冗餘」協調開傘：**主決策、備補位**。

### 5.1 實體層（USART2，硬體 UART）

兩板各跑 `LINK_BAUD = 38400` 的 USART2（PA2=TX/PA3=RX），於排線把 TX/RX 交叉一次
（A.PA2→B.PA3、A.PA3→B.PA2）即可對接。F407 USART 無硬體腳位對調，故用排線交叉取代
「韌體互換腳位」，換取硬體 UART 的可靠度（不走軟體 bit-bang）。

### 5.2 協定（`link_proto.h` / `link_proto.c`，純邏輯）

板間封包沿用遙測框架慣例，但**用不同 sync（0xC3,0x3C）**與下行遙測（0xA5,0x5A）區隔，避免
地面站把兩種封包混淆。**固定長度 26 bytes**：

```
sync0 sync1 board_id seq fsm_state flags  tick_ms  h_est_cm v_est_cms baro_alt_cm a_z_cg  crc16
  1     1      1      1      1       1       4         4         4          4        2       2   = 26 bytes
```

`flags` 直接重用 `telemetry.h` 的 `TELEM_FLAG_*`（單一真相來源），備板據 `DROGUE_FIRED` /
`MAIN_DEPLOYED` 判斷主板是否已開傘。收端 `LinkRx_Feed()` 是逐位元組狀態機，內建 sync 對齊與
CRC-16/CCITT-FALSE 校驗，框架破損會自動重新找 sync。

### 5.3 不對稱開傘仲裁：`BackupGate`（`link.h` / `link.c`，純邏輯）

這是備援設計的核心，刻意保持純函式以便 `tests/test_link.c` 鎖定行為：

- **對端狀態鎖存**：`LinkPeer_OnPacket()` 一旦收到主板的開傘旗標，就**鎖存**
  `drogue_latched` / `main_latched`（即使之後鏈路掉線仍維持，因共用點火頭已被主板點過）。
- **備板點火閘**：`BackupGate_Step()` 每飛控週期呼叫一次。語意是：

  ```
  若 對端已開（peer_latched） → 永久抑制本事件（主板已點，二極體 OR 同一點火頭，避免雙擊）
  否則 本板 FSM 想開 → 起算寬限期 BACKUP_GRACE_MS（300 ms）
        寬限內收到對端開傘 → 抑制
        寬限到期仍沒收到（主板漏點 / 失聯） → 備板自行點火一次（之後不重複）
  ```

換句話說：**正常情況以主板為準、備板閉嘴；只有主板真的沒動作或失聯，備板才在 300 ms 後補位。**
這同時解決了「共用一個點火頭不能被點兩次」與「主板失效時仍要有人開傘」兩個矛盾需求。

---

## 6. 雙鏈路二進制遙測協定

下行遙測同時走兩條 LoRa 鏈路做冗餘：

| | E22-400T30S | E80-900M2213S |
|---|---|---|
| 頻段 | 433 MHz | 920 MHz |
| 介面 | UART3 透傳 | SPI3（SX126x 命令式） |
| 驅動 | `lora_e22.c` | `lora_e80.c` |
| 現況 | 運作中 | **停用**（與 Flash 共用 SPI3，RF 參數待上板；見第 1.1 節故障隔離） |

### 6.1 封包格式（`telemetry.h`）

**固定 79 bytes、packed、結尾 CRC-16/CCITT-FALSE**（poly=0x1021, init=0xFFFF,
無反射, xorout=0x0000）。sync = `0xA5,0x5A`。所有浮點量乘倍率轉整數（避免 `%f` 吃堆疊/CPU）：

| 量 | 單位/倍率 |
|---|---|
| BMI088 加速度 | mg（g×1000） |
| BMI088 角速度 | dps |
| ADXL375 高 G | cg（0.01g，×100；±200g 用 cg 防溢位） |
| 磁場 | mGauss（×1000，機體軸） |
| 高度/速度 | cm / (cm/s)（m×100） |
| 四元數 | ×10000 |

封包含 EKF 高度/速度/四元數、氣壓、IMU/高G/磁/GPS、電池、CPU 佔用、以及兩組健康位
（`health_bits` = EKF、`sensor_bits` = 感測器）與 `flags`：

```c
#define TELEM_FLAG_DROGUE_FIRED  0x01  #define TELEM_FLAG_MAIN_DEPLOYED 0x02
#define TELEM_FLAG_SD_ACTIVE     0x04  #define TELEM_FLAG_GPS_STALE     0x08
#define TELEM_FLAG_EKF_UNHEALTHY 0x10  #define TELEM_FLAG_SENSOR_FAULT  0x20
#define TELEM_FLAG_FAILSAFE      0x40  #define TELEM_FLAG_HOTSTART      0x80
```

### 6.2 收端對齊（`telem_rx.h`）
地面端逐位元組掃 `0xA5,0x5A` 對齊封包邊界、以 `seq` 偵測丟包、以 `crc16` 校驗，CRC 失敗自動
滑窗重新對齊。**同一套邏輯在 C（韌體）與 Python（`GroundStation/telemetry_decoder.py`）各實作一份**，
契約由 `tests/test_telem_rx.c` 與 `tests/test_telemetry.c` 鎖定。

---

## 7. 地面站 ROLE_GROUND

地面站硬體與航電板相同，但只做**接收與記錄**，不參與飛控。入口 `ground_station.c`：
`main.c` 的 `defaultTask` 在 `IS_GROUND` 時呼叫 `GroundStation_Run()`（不返回）。

職責：
- **雙鏈路 RX**：E22 433（UART3 透傳，`GroundStation_OnUart3RxEvent` 推入位元組環形緩衝）
  與 E80 920（SPI3 讀 FIFO），各自餵進 `telem_rx` 解析。
- **自身 GPS**（USART6）：地面站也有 GPS，用於對齊時間/位置基準。
- **時間對齊** `gs_timesync.h`：把兩條鏈路與自身 GPS 的時間戳對齊（契約由 `tests/test_gs_timesync.c` 驗證）。
- **記錄** `gs_log.c`：SD（CSV）+ Flash（二進位 append）雙路；`tests/test_gs_log.c` 驗證格式。
- **USB-CDC**：`FEATURE_USB_CDC` 開啟，把收到的遙測 + 自身 GPS 串流給 PC。飛行版不啟用
  （`MX_USB_DEVICE_Init` 被守住，不列舉、不進 USB 中斷、不佔 CPU）。

---

## 8. 主機端純邏輯測試體系

所有「純邏輯」（不依賴 HAL/RTOS/硬體）都抽成可在電腦上編譯執行的模組，**無需上板即可驗證飛控
邏輯**。`tests/Makefile` 用系統 `cc`、`-I../Main_Code/Core/Inc`、`-std=c11`、`-lm`，
與韌體共用同一份 header/.c。執行：`make host-test`（= `make -C tests run`，任一失敗即非零中止）。

目前 12 個測試：

| 測試 | 驗證對象 |
|---|---|
| `test_sensor_axis` | 軸向對應為合法旋轉（行列式 +1） |
| `test_fsm` | 飛行狀態機：升空/頂點/開傘/落地情境 |
| `test_ekf_guard` | EKF 健康位邏輯 |
| `test_sensor_health` | 感測器失流/卡死/範圍失效門檻 |
| `test_telemetry` | 79-byte 封包打包 + CRC16 |
| `test_telem_rx` | 收端 sync 對齊/重組/自動重對齊 |
| `test_gs_timesync` | 地面站時間對齊 |
| `test_gs_log` | 地面站 CSV 記錄格式 |
| `test_gps` | NMEA GGA/RMC 解析 |
| `test_flash_ring` | Flash 環形指標迴繞數學 |
| `test_link_proto` | 板間 26-byte 封包組/解 + sync 區隔 |
| `test_link` | 不對稱備援 BackupGate 仲裁 |

---

## 9. Python 工具鏈

| 腳本 | 用途 |
|---|---|
| `serial_link.py` | 統一串口設定/自動偵測（其他腳本共用，2026-06-12 收斂三份重複邏輯而來） |
| `test_runner.py` | HIL 自動化：編譯 → 燒錄 → 監聽 → 斷言 |
| `ekf_visualizer.py` | EKF 軌跡/姿態即時 3D 視覺化 |
| `gui_monitor.py` | 即時遙測 GUI 顯示 |
| `GroundStation/telemetry_decoder.py` | 獨立 79-byte 解碼器（地面 PC 端，與韌體 `telem_rx` 同契約） |

---

## 10. 如何修改代碼

### 10.1 新增感測器
1. CubeMX 設定 CS / I2C 腳位並生成代碼。
2. 參考 `adxl375.c` 寫初始化與物理值讀取。
3. 高頻採樣加入定時器中斷、寫入 Ping-Pong 寫入端；低頻則於主迴圈輪詢。
4. 在 `sensor_axis.h` 補上「原生軸 → 機體軸」對應，並加 `tests/` 測試。

### 10.2 改開傘參數
打開 `Main_Code/Core/Inc/fsm.h`，改 `LIFTOFF_ACCEL_THRESHOLD`、`TARGET_MAIN_ALTITUDE`
等巨集，必要時在 `fsm.c` 的 `FSM_Step()` 調整轉移規則。改完跑 `make host-test`（`test_fsm`）驗證。

### 10.3 切換角色重編
改 `board_config.h` 的 `BOARD_ROLE`，或直接 `make build-backup` / `make build-ground`。

> 注意 `docs/改進計劃.md` 的待辦：`FSM_FAILSAFE_APOGEE_MS` 等失效保護計時必須以 OpenRocket
> 模擬重推後才可上飛，不可沿用預設值。

---

## 11. 編譯與工具鏈

- **工具鏈**：必須用 **STM32CubeIDE 內建的 arm-none-eabi gcc**，**不可用 Homebrew 版**
  （頂層 `Makefile` 會自動從 CubeIDE plugins 路徑偵測 gcc 與 `STM32_Programmer_CLI`）。
- **常用指令**：`make`（編譯）、`make flash`（ST-Link SWD 燒錄）、`make monitor`
  （自動偵測序列埠 @460800，可用 `PORT=/dev/cu.xxx` 覆寫，Ctrl+A K 離開）、`make host-test`、`make clean`。
- **編譯四步**：預處理 → 編譯（.s）→ 彙編（.o）→ 連結（.elf/.bin）。
- **CubeIDE 路徑**：手動新增原始碼後，於 C/C++ General → Paths and Symbols 把 header 目錄加入
  Include Paths、`.c` 目錄加入 Source Location，否則找不到檔。

---

## 延伸閱讀（皆在 `docs/`）

- `docs/連線和基本硬體規格表.md` — 接腳/匯流排黃金真相（含 I2C 腳位互換警告）。
- `docs/改進計劃.md` — P0–P3 飛行安全改進計劃與上飛前檢查清單。
- `docs/設計_ADXL375_EKF融合與SPI1並發.md` — ADXL 融合 / SPI1 並發的上板設計筆記。
- `docs/測試方法.md`、`docs/需求_驗證.md` — 測試環境與需求驗證矩陣。
- 根目錄 `PROJECT_HISTORY.md` — 專案演進史與重大決策的「為什麼」。

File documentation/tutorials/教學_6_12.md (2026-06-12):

# RocketCom 航電系統：從零開始點亮 LED、序列輸出與感測器 SPI 驅動教學

本教學手冊旨在引導成大 ISP 航電組在 **STM32F407VGT6** 主控板上進行軟韌體開發，涵蓋最基本的 GPIO 操作、看門狗餵狗防禦、IMU (BMI088) 驅動、高-G 加速度計 (ADXL375) 與氣壓高度計 (BMP388/390) 的 SPI 驅動與高頻中斷雙緩衝優化。

---

## 🚀 系統硬體與軟體規格簡介

* **核心主控**：STM32F407VGT6 (LQFP100)
* **開發工具**：STM32CubeIDE + STM32CubeMX
* **作業系統**：FreeRTOS (CMSIS_V2)
* **安全防範**：獨立看門狗定時器 (IWDG)

---

## 🚀 階段一：點亮第一個心跳 LED (GPIO 輸出)

為了驗證核心最小系統正常工作，第一步通常是點亮並翻轉板載的 `LED_SYS`。

### 1. 硬體引腳連接
* **Net Label**: `LED_SYS` -> **`PE2`**
* **控制邏輯**: 低電平 (Low) 點亮，高電平 (High) 熄滅。

### 2. FreeRTOS 任務實作
在預設任務（Default Task）中，我們實作溫和的 **1 Hz 系統心跳 (Heartbeat) 指示**：

```c
void StartDefaultTask(void *argument)
{
  for(;;)
  {
    // 翻轉 PE2 引腳狀態
    HAL_GPIO_TogglePin(LED_SYS_GPIO_Port, LED_SYS_Pin);
    
    // 延遲 500ms (形成亮 0.5s / 暗 0.5s)
    osDelay(500);
  }
}
```

---

## 🚀 階段二：USART2 序列輸出與 printf 重定向

為了讓航電板能透過 UART 輸出日誌到電腦進行除錯，我們需要重定向 `printf`。

### 1. `printf` 重定向至 USART2 (`PA2`/`PA3`)
在 `main.c` 的 `USER CODE BEGIN 4` 區塊中定義 `_write` 函數：

```c
int _write(int file, char *ptr, int len)
{
  HAL_UART_Transmit(&huart2, (uint8_t*)ptr, len, HAL_MAX_DELAY);
  return len;
}
```

### 2. 避免使用浮點數以節省資源
在嵌入式系統中，`printf` 輸出 `%f` 浮點數非常消耗堆疊空間與 CPU 資源。我們採用乘上倍率轉為整數輸出的黃金法則：
* **加速度數據**：乘上 `1000.0f`，轉為 **milli-g (毫重力)** 整數輸出。
* **高度數據**：乘上 `100.0f`，轉為 **cm (公分)** 整數輸出。
* **溫度數據**：乘上 `100.0f`，轉為 **°C * 100** 整數輸出。

---

## 🚀 階段三：看門狗 (IWDG) 超時防禦與除錯調整

### 1. 發現問題
在除錯放慢主迴圈時，Live Expressions 中的數據常會莫名歸零並重置，這是因為看門狗（IWDG）超時觸發了硬體 Reset。

### 2. 解決方案
在 FreeRTOS 主任務無窮迴圈的頂端，必須定期呼叫餵狗指令：

```c
  for(;;)
  {
    // 餵狗 (Feed the independent watchdog)
    HAL_IWDG_Refresh(&hiwdg);
    
    // 讀取感測器...
  }
```

---

## 🚀 階段四：BMI088 標準姿態 IMU (SPI2 整合)

BMI088 提供 $\pm 24g$ 加速度與 $\pm 2000^\circ/	ext{s}$ 角速度，掛載於 **SPI2**。
* **ACCEL_CS** -> `PB12`
* **GYRO_CS** -> `PB11`
* **SPI2_SCK** -> `PB13` (在驅動中需注意時鐘空閒狀態的配置與穩定性)。

---

## 🚀 階段五：ADXL375 高-G 加速度計 (SPI1 整合)

ADXL375 提供 $\pm 200g$ 的衝擊加速度，掛載於 **SPI1**。
* **HIGHG_CS** -> `PC4`
* 解析度固定為 **49 mg/LSB**。
* 注意事項：因為 PCB 走線軸向相反，實際解算時 X 與 Y 軸數據應取負值以做方向修正。

---

## 🚀 階段六：BMP388/390 氣壓高度計 (官方 Bosch BMP3 API 完美整合)

BMP388 掛載於 **SPI1**，負責氣壓、溫度與厘米級相對高度。
* **BARO_CS** -> `PA4`

### 1. 為何引進官方 Bosch BMP3 Sensor API (v2)？
Bosch 晶片的校準多項式具有極高精度的量產量化要求（如 $2^{-8}$、$2^{-30}$ 等），手動實現極易因精度損失導致嚴重偏差。我們直接引進官方維護的 BMP3 API（`bmp3.c`、`bmp3_defs.h`），以獲得絕對精確的補償解算。

### 2. 轉換時間與 ODR 限制關係
根據 Datasheet 規定，氣壓計的轉換時間為：
$$T_{conv} = 234\mu s + press\_en \cdot (392\mu s + 2^{osrs\_p} \cdot 2000\mu s) + temp\_en \cdot (313\mu s + 2^{osrs\_t} \cdot 2000\mu s)$$
* 在 **200 Hz ODR (5ms 週期)** 下，我們 must 採用 **1x 氣壓過採樣** 與 **1x 溫度過採樣**：
  $$T_{conv} = 234 + (392 + 2000) + (313 + 2000) = 4939\mu s = 4.94	ext{ ms} < 5	ext{ ms}$$
  這符合 $T_{conv} < T_{ODR}$ 的限制，官方 API 驗證通過，順利啟動。

---

## 🚀 階段七：飛控級高頻中斷採樣與雙緩衝 (TIM3 + Ping-Pong Buffer ADXL375 實作)

為了解鎖 `ADXL375` 的 3200 Hz 理論最高 ODR，且不干擾 RTOS 任務的正常排程，我們引進了**定時器中斷 + 雙緩衝區（Ping-Pong Buffer）**架構。

### 1. TIM3 3.2 kHz 定時器配置
* **時鐘計算**：TIM3 輸入時鐘為 **$84	ext{ MHz}$**。
* **參數設定**：
  * `Prescaler = 5`（6 分頻，時鐘變為 $14	ext{ MHz}$）。
  * `Period = 4374`（4375 計數）。
  * 頻率計算：
    $$f_{TIM3} = 
rac{84,000,000}{6 	imes 4375} = \mathbf{3200.0	ext{ Hz}}$$

### 2. Ping-Pong 雙緩衝機制
* 聲明一個雙緩衝陣列：`ADXL_Sample_t g_adxl_batches[2][32];`。
* **中斷阻塞讀取**：TIM3 中斷觸發後，在中斷內直接拉低 `PC4` (HIGHG_CS) 透過 SPI1 讀取 7 位元組原始數據（10 MHz 下僅耗時 **$5.6\mu s$**，僅佔週期的 **$1.8\%$**，對中斷極其安全）。
* **批次打包通知**：當寫入滿 32 筆資料（10 ms）時，自動切換緩衝區，並設置 `g_adxl_new_batch_ready = 1`。
* **RTOS 低頻處理**：FreeRTOS 任務在 1ms 循環內查詢該 Ready 標誌並一次性取出批次數據（可直接進行 3.2 kHz 批次持久化），將 RTOS 切換開銷降低 96.8%（從 3200 Hz 降至 100 Hz）！

### 3. SPI1 總線互斥安全鎖
* **衝突場景**：由於 ADXL375 (定時器中斷讀取) 與 BMP388 (RTOS 任務) 共用 SPI1。如果任務正在讀取 BMP388，TIM3 中斷搶佔總線將導致衝突。
* **解決方案**：在 `main.c` 任務讀取 `BMP388_ReadData` 的前後，封裝中斷屏蔽鎖：
  ```c
  __HAL_TIM_DISABLE_IT(&htim3, TIM_IT_UPDATE);  // 暫停 TIM3 中斷
  BMP388_ReadData(&hspi1, &baro_data);          // 讀取 BMP388
  __HAL_TIM_ENABLE_IT(&htim3, TIM_IT_UPDATE);   // 恢復 TIM3 中斷
  ```
  由於 BMP388 傳輸僅需約 $20\mu s$，TIM3 中斷暫停不會漏失數據（中斷標誌會保持 Pending，重開後立即追補執行），完美保證了 SPI1 匯流排的絕對安全！

---

## 🚀 階段八：飛控級高頻中斷採樣與雙緩衝 (TIM6 + TIM7 + Ping-Pong Buffer BMI088 1600+2000 Hz 實作)

為了將標準姿態 IMU `BMI088` (加速度計最高實體 ODR=1600 Hz，陀螺儀最高實體 ODR=2000 Hz) 發揮到各自的物理極限，且不讓超高頻傳感器讀取浪費 RTOS 任務排程時間，我們採用了**雙定時器獨立中斷 + 獨立 Ping-Pong 雙緩衝**的高性能解耦架構。

### 1. 雙定時器配置
TIM6 與 TIM7 均掛載在 APB1，輸入時鐘為 **$84	ext{ MHz}$**：
- **TIM6 (加速度計 1600 Hz)**：
  - `Prescaler = 41`（42 分頻，時鐘 2 MHz）。
  - `Period = 1249`（1250 計數）。
  - 頻率：$2,000,000 / 1250 = \mathbf{1600.0	ext{ Hz}}$。
- **TIM7 (陀螺儀 2000 Hz)**：
  - `Prescaler = 41`（42 分頻，時鐘 2 MHz）。
  - `Period = 999`（1000 計數）。
  - 頻率：$2,000,000 / 1000 = \mathbf{2000.0	ext{ Hz}}$。

### 2. 獨立雙緩衝機制
- **加速度計**：`g_bmi_acc_batches[2][16]`（16 筆數據為一個 10ms 批次）。在 TIM6 中斷內呼叫 `BMI088_ReadAccel` 阻塞讀取 6 位元組加速度（耗時僅約 **$5.6\mu s$**），集滿後設置 `g_bmi_acc_new_batch_ready = 1`。
- **陀螺儀**：`g_bmi_gyro_batches[2][20]`（20 筆數據為一個 10ms 批次）。在 TIM7 中斷內呼叫 `BMI088_ReadGyro` 阻塞讀取 6 位元組角速度（耗時僅約 **$5.2\mu s$**），集滿後設置 `g_bmi_gyro_new_batch_ready = 1`。
- **RTOS 數據提取**：在 `StartDefaultTask` 中，每隔 1ms 輪詢兩個標誌，集滿時非阻塞提取各自最後一筆最新採樣數據供 20 Hz 即時遙測傳輸。

### 3. SPI2 零鎖定衝突免除設計 (Zero-Lock Bus Dedication)
- **架構優勢**：因為 **SPI2 匯流排完全專屬於 BMI088 加速度與陀螺儀**，FreeRTOS 的任何其他任務都不會使用 SPI2。
- **安全保障**：我們將 SPI2 的所有操作都封裝進 `TIM6_DAC_IRQHandler` 與 `TIM7_IRQHandler` 中，徹底免除了 RTOS 任務層的呼叫。因此，中斷在讀取時，**絕對不會與任何 FreeRTOS 任務發生 SPI 匯流排搶佔衝突**。
- **性能收益**：完全不需要中斷屏蔽鎖（`__HAL_TIM_DISABLE_IT`）或互斥鎖，以物理硬體定時器優勢實現了零死鎖、零開銷、超低抖動的飛控級數據獲取。

---

## 🚀 階段九：人機交互與狀態 LED 心跳指示優化

* **改善**：已將系統 LED 翻轉解耦，從原本與 50ms 遙測輸出綁定改為獨立配置：
  ```c
  /* 每 500ms 翻轉 LED 一次，形成溫和的 1 Hz 視覺心跳 (0.5s 亮 / 0.5s 暗) */
  if (tick % 500 == 0) {
      HAL_GPIO_TogglePin(LED_SYS_GPIO_Port, LED_SYS_Pin);
  }
  ```
* **效果**：提供更為穩健舒緩的 1 Hz 心跳信號指示，同時大幅優化了現場除錯的視覺體驗。

---

## 🚀 階段十：SD 卡高速 SDIO 數據日誌記錄與插卡防空保護 (FATFS 整合)

為了解鎖飛行數據的實時本地持久化，我們將板載 SD 卡槽（掛載於 SDIO 匯流排）與 FatFs 文件中間件進行整合，實現了啟動後 10 秒 100 Hz CSV 高頻遙測日誌的儲存。同時，為了相容無卡 HIL 測試，我們設計了防空保護引腳邏輯。

### 1. FatFs 與 SDIO 延遲掛載
在 `StartDefaultTask` 啟動時，使用非阻塞的延遲掛載，確保絕不因外部 SDIO 狀態阻塞 FreeRTOS 看門狗（IWDG）：
```c
  // 延遲掛載參數為 0 (不要立即物理掃描卡)，保證非阻塞
  if (f_mount(&SDFatFS, SDPath, 0) == FR_OK) {
      // 順利註冊 FatFs 磁碟區
  }
```

### 2. 物理插卡檢測與無卡防空鎖死保護
* **衝突痛點**：如果 SD 卡未插入，但 `SDIO_DET` 引腳浮空（Floating）讀取為 0，FatFs 的 `f_open` 會進入物理總線讀寫，在 DMA 傳輸中因無響應而永久卡死或超時，導致串口遙測無法啟動，甚至看門狗復位。
* **解決方案**：
  1. 將 `SDIO_DET_Pin` (PD3) 引腳配置由 `GPIO_NOPULL` 修改為 **`GPIO_PULLUP`**，確保當沒有 SD 卡插入時，PD3 被內部強拉為高電平 (1)，而有卡插入時被金屬彈片下拉為低電平 (0)。
  2. 在掛載後，檢測 `SDIO_DET` 狀態。只有為低電平時才執行 `f_open` 建立日誌，否則優雅跳過：
```c
  if (HAL_GPIO_ReadPin(SDIO_DET_GPIO_Port, SDIO_DET_Pin) == GPIO_PIN_RESET) {
      printf("[SD] ✅ 檢測到 SD 卡已插入！正在建立 HIL_10S.CSV 檔案...
");
      if (f_open(&SDFile, "HIL_10S.CSV", FA_CREATE_ALWAYS | FA_WRITE) == FR_OK) {
          sd_logging_active = 1;
          sd_log_start_tick = HAL_GetTick();
          // 寫入 CSV Header
          char header[] = "tick_ms,bmi_ax,bmi_ay,bmi_az,adxl_ax,adxl_ay,adxl_az,temp,press,alt
";
          UINT bw;
          f_write(&SDFile, header, sizeof(header) - 1, &bw);
      }
  } else {
      printf("[SD] ⚠️ 未檢測到 SD 卡插入（SDIO_DET 為高電平），跳過 10 秒日誌寫入。
");
  }
```

### 3. 10 秒 100 Hz CSV 高頻寫入與安全卸載
在 Default Task 循環中，若 `sd_logging_active` 裝態啟用，利用 `tick` 計數器進行 100 Hz (10ms) 分頻寫入：
```c
  if (sd_logging_active) {
      uint32_t current_elapsed = HAL_GetTick() - sd_log_start_tick;
      if (current_elapsed < 10000U) { // 限制為 10 秒
          if (tick % 10 == 0) { // 100 Hz (10ms) 寫入一次
              char csv_buf[128];
              int len = snprintf(csv_buf, sizeof(csv_buf), "%u,%d,%d,%d,%d,%d,%d,%d,%d,%d\r\n", ...);
              UINT bytes_written;
              f_write(&SDFile, csv_buf, len, &bytes_written);
          }
      } else {
          // 滿 10 秒，關閉並儲存檔案，卸載 FatFs，徹底將緩衝寫回磁碟，避免數據丟失
          f_close(&SDFile);
          f_mount(NULL, SDPath, 1); // 強制卸載 (1)
          sd_logging_active = 0;
          printf("[SD] 🎉 10 秒數據寫入結束！檔案已安全關閉並儲存 (HIL_10S.CSV)。\r\n");
      }
  }
```
這套架構在保護了 HIL 測試的流暢度的同時，也保證了實體發射時黑盒子數據日誌的極高可靠性與實時性能！

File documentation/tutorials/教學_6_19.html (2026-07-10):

🏠 學習大廳 📖 語法字典 🔍 原始碼逐行解析 🎮 FSM 模擬器 🔢 位元運算沙盒 🔄 任務與排程模擬 ⚙️ 編譯與修改指引

NC ISP 航電課程

# RocketCom 航電系統與 C 語言互動式學習中心

本平台專為飛控系統與 C/C++ 初學者設計。我們將結合專案真實原始碼，為您提供無死角的逐行指令解析與豐富的硬體時序模擬工具。

🗺️ 航電學習路線圖 (Avionics Learning Path)

步驟一：熟悉 C 語言基礎

閱讀 語法字典，並動手玩 位元運算沙盒，掌握暫存器位移、位元與、位元或等硬體拼接細節。

步驟二：理解系統架構

閱讀 任務與排程模擬，掌握硬體定時器中斷（TIM3/TIM6/TIM7）時序與 FreeRTOS 多任務非同步日誌佇列流程。

步驟三：精讀核心代碼

開啟 原始碼逐行解析，結合 FSM 狀態機模擬器，對照每一行指令，透徹理解火箭點火與開傘的邏輯判斷條件。

步驟四：配置編譯與動手修改

研讀 編譯與修改指引，了解 GCC 編譯、Makefile 增量編譯，以及 STM32CubeIDE include 與 source 路徑配置。

## 📖 C/C++ 語法字典與專用術語

點擊下方術語或語法關鍵字，即可在右側查看其在航電系統開發中的具體應用與原理解析：

C/C++ 語法特徵

航電專用術語

💡

### 請點擊左側字彙

點擊左側目錄即可在此載入其在 STM32 飛控專案中的詳細硬體意義與代碼案例說明。

#### 原始碼模組

## 🎮 有限狀態機 (FSM) 模擬沙盒

#### 飛控狀態變數調整

卡爾曼高度 (h_est)

0 m

卡爾曼垂直速度 (v_est)

0 m/s

IMU 垂直加速度 (a_z)

1 G

系統定時器 (tick_ms)

0s

當前狀態機狀態 (FSM State) PAD (發射架)

火箭在發射架上等待發射。此時垂直速度為 0，高度為 0。

狀態機判定程式分支 (C Code)

## 🔢 互動式暫存器位元運算沙盒

ADXL375 加速度計是將讀數拆分為 LSB 和 MSB 兩個 8 位元暫存器。點擊下方 16 位元暫存器方格切換 Bit 狀態，觀看位移 << 8 和按位或 | 運算的過程與二進制補碼轉換結果：

高位暫存器 MSB (rx_buf[1]) 0x00

低位暫存器 LSB (rx_buf[0]) 0x00

位元組拼裝運算時序 (Bit Shifting & Merging)

1. 左移高位位元組 (rx_buf[1] << 8): 00000000 00000000

2. 按位與低位位元組 (| rx_buf[0]): 00000000 00000000

解碼結果 (raw_val): 0 (有號 16 位元有號整數 int16_t)

物理加速度 (G): 0.00 G (raw_val * 49 mg/LSB)

## 🔄 中斷定時器與雙緩衝/佇列排程模擬

#### 中斷 Ping-Pong 雙緩衝模擬

高頻定時中斷 TIM3 (3.2kHz) 在背景向緩衝區寫入資料。寫滿 32 格時，自動切換緩衝區索引，使前景任務 `defaultTask` 可在無鎖狀態下安全讀取，避免資料撕裂。

定時器 TIM3 (3.2kHz) 計數：0 / 32 活動緩衝區：緩衝區 A

⚡ 觸發一次 TIM3 中斷 ⚡ 快速寫滿一個 Batch (32次)

緩衝區 A

緩衝區 B

#### FreeRTOS 非同步日誌佇列模擬

在真正的非同步架構中，1kHz 飛控任務發送指標給 FreeRTOS 隊列。本模擬展示在 10Hz 下 EKF 數據打包推入隊列，由日誌任務讀出寫入 SD 卡，即使 SD 卡發生垃圾回收 GC 阻塞（拉高 Busy 時間），佇列也能緩衝防溢出。

佇列容量 (xEKFQueue)：0 / 5 SD卡 Busy狀態：閒置中 (FR_OK)

📥 寫入並推入一筆數據包 📤 讀取並寫入 SD 卡 ⚠️ 模擬 SD卡 GC 阻塞 (150ms)

## ⚙️ 編譯配置與自訂修改指引

#### 1. C 語言編譯的四個關鍵步驟

1. 預處理 (Preprocessing)：替換所有 #define 巨集並展開 #include 標頭檔。生成 .i 文件。
2. 編譯 (Compilation)：將預處理後的 C 代碼優化並翻譯成 ARM 組合語言程式碼，生成 .s 文件。
3. 彙編 (Assembly)：將組合語言翻譯成二進位機器碼，生成物件檔案 .o（含相對編譯位址）。
4. 連結 (Linking)：連結器根據 .ld 連結腳本，將各個編譯好的 .o 檔案定位到晶片實體 Flash 和 RAM 位址中，生成最終 .elf / .bin 韌體鏡像。

#### 2. 什麼是 Make 與 Makefile

- Makefile 定義了物件檔案（.o）與其對應原始碼（.c、.h）之間的依賴與編譯命令。
- Make 工具藉由比較依賴檔案的修改時間戳記，實行增量編譯（只重編譯自上次建置以來被修改過的文件）。大為縮短調試與編譯時長。

#### 3. STM32CubeIDE 路徑配置

當您手動新增自訂代碼檔案（例如 `my_sensor.c`）到專案中時，若未正確配置，編譯器將無法搜索到它：

- Include paths：進入 Properties -> C/C++ Build -> Settings -> Tool Settings -> MCU GCC Compiler -> Include paths 新增頭文件路徑，否則預處理會發生 No such file or directory 錯誤。
- Source location：進入 Properties -> C/C++ General -> Paths and Symbols -> Source Location 將包含 .c 的資料夾加入 Source Location，否則連結器在最終編譯時會回傳 Undefined reference 連結錯誤。

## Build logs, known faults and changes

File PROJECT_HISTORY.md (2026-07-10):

# RocketCom 專案演進史

> 本檔以時間軸記錄 RocketCom 航電專案的重大決策與轉折，重點在「**為什麼這樣做**」與
> 「**對飛行安全/可靠度的影響**」，而非逐筆 commit。逐次開發流水帳見 `docs/進度.md`，
> 程式碼層面的講解見 `教學/教學_6_24.md`。日期以 git log 與 `docs/進度.md` 為準。
>
> 遵循 `docs/AI_output_requirement.md`：不使用 emoji、不截斷重要輸出。

---

## 一、硬體與專案起步（2026-05-25 ~ 05-26）

專案以一套 STM32F407 航電板起步，主板規劃為四層結構（`top` 介面層、`mainmcu` 主控、
`lora` 射頻、`newpower` 電源），外加獨立的開傘部署板。

- **為什麼是 STM32F407VGT6 + BMP388**：原先選用的氣壓計與 MCU 因**元件短缺**無法穩定供貨，
  改用 F407VGT6 與 BMP388（並在規格表記下「BMP388 非 BMP390」的替代注意事項）。這也是後來
  所有接腳/匯流排都以 `docs/連線和基本硬體規格表.md` 為「黃金真相」的起點——從原理圖 100%
  萃取，避免日後憑記憶接線。
- **成本最佳化**：為省成本設計了二合一合併板 `Production_MCU_TOP_2_in_1`，首批 5 張板送印。
- 接著把專案遷入 STM32CubeIDE（`Main_AV_F407` → 後更名 `Main_Code`），完成 CubeMX 的 NVIC、
  DMA、FreeRTOS、FATFS 核心配置——這份 `.ioc` 等於整個系統的硬體骨架交接規格書。

---

## 二、感測器與高頻採樣 bring-up（2026-05-27）

這一天密集完成多顆感測器的實體驗證，奠定「高頻採樣」的工程基礎：

- **BMI088（SPI2）IMU 驅動**上線；同時實作 `printf` 重定向到 USART2（115200），用 20 Hz CSV
  即時輸出感測值，支援串口波形監控與 Python 自動化——**這個除錯通道貫穿了後續整個開發**。
- **高頻定時器中斷 + Ping-Pong 雙緩衝**：ADXL375 經 TIM3 跑到 **3200 Hz** 理論極限；BMI088
  經 TIM6/TIM7 跑到加速度 **1600 Hz**、陀螺 **2000 Hz**。雙緩衝的意義是**消除資料撕裂**
  （讀到半新半舊的三軸值），讓前景任務無鎖讀取穩定批次。
- **可靠度基礎件**：`rate_monitor.h` 讓所有感測器實測 Hz 一眼可視；**IWDG 看門狗 2.0 s**
  快速超時，主迴圈每 1 ms 餵狗，保障飛行中死機能快速復位。
- **資料儲存兩條路**：W25Q128 SPI Flash 環形緩衝（52-byte packed 封包、CRC-16、開機二元搜尋
  恢復寫入頭，斷電可續寫）＋ SD 卡 CSV 日誌（檔名自動遞增、修正延遲掛載導致的 `FR_NOT_READY`）。

---

## 三、飛行狀態機與第一版飛控（2026-05-30 ~ 06-01）

- **七狀態 FSM**：實作升空偵測、動態預測式頂點與主傘部署、以及邊界安全的熱重啟恢復雛形。
- **Buzzer 開機提示音**：TIM2 PWM 兩聲漸高；過程修掉 TIM2 32-bit ARR overflow 導致蜂鳴器停響
  的 bug（以 `EGR=UG` 強制歸零 CNT）。
- **全程記錄（FSM 驅動）**：移除原本 10 秒上限，改成升空到落地 100 Hz、落地後降 10 Hz 續錄，
  避免錯過任何階段。為此特意**不在落地時 `vTaskSuspend`**，讓遙測/Flash/尋標蜂鳴器持續運作。

---

## 四、EKF 融合與「接錯線」實戰救援（2026-06-01 ~ 06-03）

這是專案最有教訓價值的一段——**多個問題其實是硬體接線與設定，不是演算法**。

- **GPS 驅動（USART6，NMEA-0183，DMA-to-idle）**上線，並在實作中**揪出計畫書把 UART 對應寫反**：
  計畫書誤標 GPS 在 USART3，但對照硬體黃金規格表，**GPS（NEO-M9N）實體在 USART6，USART3 其實是
  E22 433 MHz LoRa**。若照錯誤計畫接線，GPS 永遠收不到資料還會與 LoRa 搶線。教訓：**以從原理圖
  萃取的規格表為準，不信任二手計畫書**。
- **EKF 融合**：GPS 水平位置（發射台鎖原點、等距投影 ENU、量測噪聲隨衛星數縮放，僅飛行中融合）、
  磁力計航向（僅發射台鎖定絕對航向、抑制陀螺 yaw 漂移）、ADXL375 在 BMI088 飽和（>20 g）時接手。
- **發現 EKF 加速度單位前置阻斷項**：IMU/ADXL 樣本是 g，但 `EKF_Predict` 以 m/s² 扣重力積分；
  靜置被校準抵銷（故 bench 正常）但**動態被低估約 9.81×**。結論寫進
  `docs/設計_ADXL375_EKF融合與SPI1並發.md`，列為上板 HIL 必先解的根因。
- **2026-06-03 重大實戰救援**：實體測試發現**電子羅盤線路接反**且 **GPS 鮑率設錯**，以軟體戰術
  定位並救回。連帶把磁力計從不穩的硬體 I2C **回歸軟體 I2C（bitbang）+ 100 Hz polling**，根治
  鎖死風險——可靠度優先於「用硬體周邊比較漂亮」。

---

## 五、全系統整合與 P0 飛行安全（2026-06-11 ~ 06-12）

`total_test` 分支把全系統整合並接上 **LoRa 雙鏈路二進制遙測**，隨後依 `docs/改進計劃.md`
的風險清單（R1–R8）做了六項 **P0 飛行安全**改進，並全數 merge 回 `main`：

- **P0-A**：把飛行狀態機抽成純邏輯模組（host 可測）——讓開傘決策能在電腦上用情境測試鎖定。
- **P0-B**：頂點失效保護 + 氣壓原始趨勢交叉檢查（修 R1，避免單一估計失準就錯過開傘）。
- **P0-C**：EKF 防護最小集 + FSM **raw-baro 降級鏈**（EKF 不健康時改用純氣壓+加速度觸發）。
- **P0-D**：感測器健康監測最小集（失流/卡死/範圍失效偵測）。
- **P0-E**：消除飛行迴圈中的阻塞（修 R6/R8，避免關鍵迴圈被慢操作卡住）。
- **P0-F**：熱啟動安全化——修「空中斷電重啟可能二次點火」（R7），以 drogue-already-fired 閂鎖
  確保已開傘事件不重觸發。

同期 **P1** 把契約與健壯性補齊：**遙測契約鎖定 + 79-byte 封包 + 地面站解碼器一次到位**；
LoRa 健壯化（消除 PD6 EXTI 中斷風暴、E22 AUX 逾時重試）；EKF 垂直發散自救（DIVERGE >3 s 重置）；
GPS NMEA 解析加固（抽純函式 + 65 host 案例）；**Flash 環形緩衝迴繞數學抽純，修掉一個資料損毀 bug**；
任務堆疊水位監測。

---

## 六、收斂與衛生（2026-06-12 ~ 06-15）

- **P2 雙 Flash 驅動合一**：把 `w25q128.c` 併入 `w25qxx.c`，消除重複驅動；清掉 `-Wall` 警告
  （packed 成員位址經對齊區中轉）。
- **P3 工具收斂**：`serial_link.py` 收斂三份腳本重複的串口邏輯；頂層 `Makefile` 加 `host-test`
  target；倉庫衛生清理。
- **2026-06-15 停用 E80 920 MHz + SPI3 單設備故障隔離**：E80 與 W25Q128 Flash **共用 SPI3**，
  為避免未完成 bring-up 的 E80 干擾飛行資料記錄，先停用 E80 並加上故障隔離（按住 RST 釋放匯流排），
  確保單一設備異常不拖垮共用匯流排。E22 433 仍為主要下行鏈路。

---

## 七、從單板到三角色：備援與地面站（2026-06 下旬，工作區進行中）

最近一階段把系統從「單一航電板」擴展為**三角色、一份程式碼**（詳見 `教學/教學_6_24.md` 第 1、5、7 節）。
以下變更目前在工作區、尚未 commit：

- **主/備雙航電不對稱備援**：新增 `board_config.h` 編譯期角色（PRIMARY/BACKUP/GROUND）與功能閘；
  兩塊相同 MCU 板以 **USART2 硬體 UART**（排線 TX/RX 交叉）互通狀態；`link.c` 的 **BackupGate**
  仲裁採「主決策、備補位」：備板判到開傘先等 300 ms，收到主板開傘通知就抑制（共用點火頭、二極體 OR
  防雙擊），主板漏點/失聯才自行補位。純邏輯由 `tests/test_link.c` / `test_link_proto.c` 鎖定。
- **地面站 ROLE_GROUND**：硬體與航電板相同，只「接收」——雙鏈路 LoRa RX + 自身 GPS，經
  `gs_timesync` 對齊時間後記錄到 SD/Flash 並以 **USB-CDC** 串流給 PC。新增 `ground_station.c`、
  `gs_log.c`、`gs_timesync.h`、`telem_rx.h` 與對應 host 測試。

至此主機端純邏輯測試達 12 個模組、約 260+ 案例，飛控關鍵邏輯皆可離板驗證。

---

## 八、待驗證／待辦（上飛前必清）

- **E80 920 MHz RF 參數**：待實體模組上板 bring-up 完成才重新啟用（目前停用）。
- **`FSM_FAILSAFE_APOGEE_MS` 等失效保護計時**：必須以 OpenRocket 模擬重推後才可上飛，不可沿用預設值
  （見 `docs/改進計劃.md`）。
- **EKF 加速度單位統一（g → m/s²）**：融合 ADXL375 動態加速度前的前置阻斷項，待 HIL 驗證。
- **磁力計軸向、GPS 收星、雙航電/地面站上板實測**：皆已編譯通過、host 測試綠，待硬體驗證。

---

*詳細逐次紀錄：`docs/進度.md`｜改進計劃與檢查清單：`docs/改進計劃.md`、`docs/待確認、改進清單.md`*

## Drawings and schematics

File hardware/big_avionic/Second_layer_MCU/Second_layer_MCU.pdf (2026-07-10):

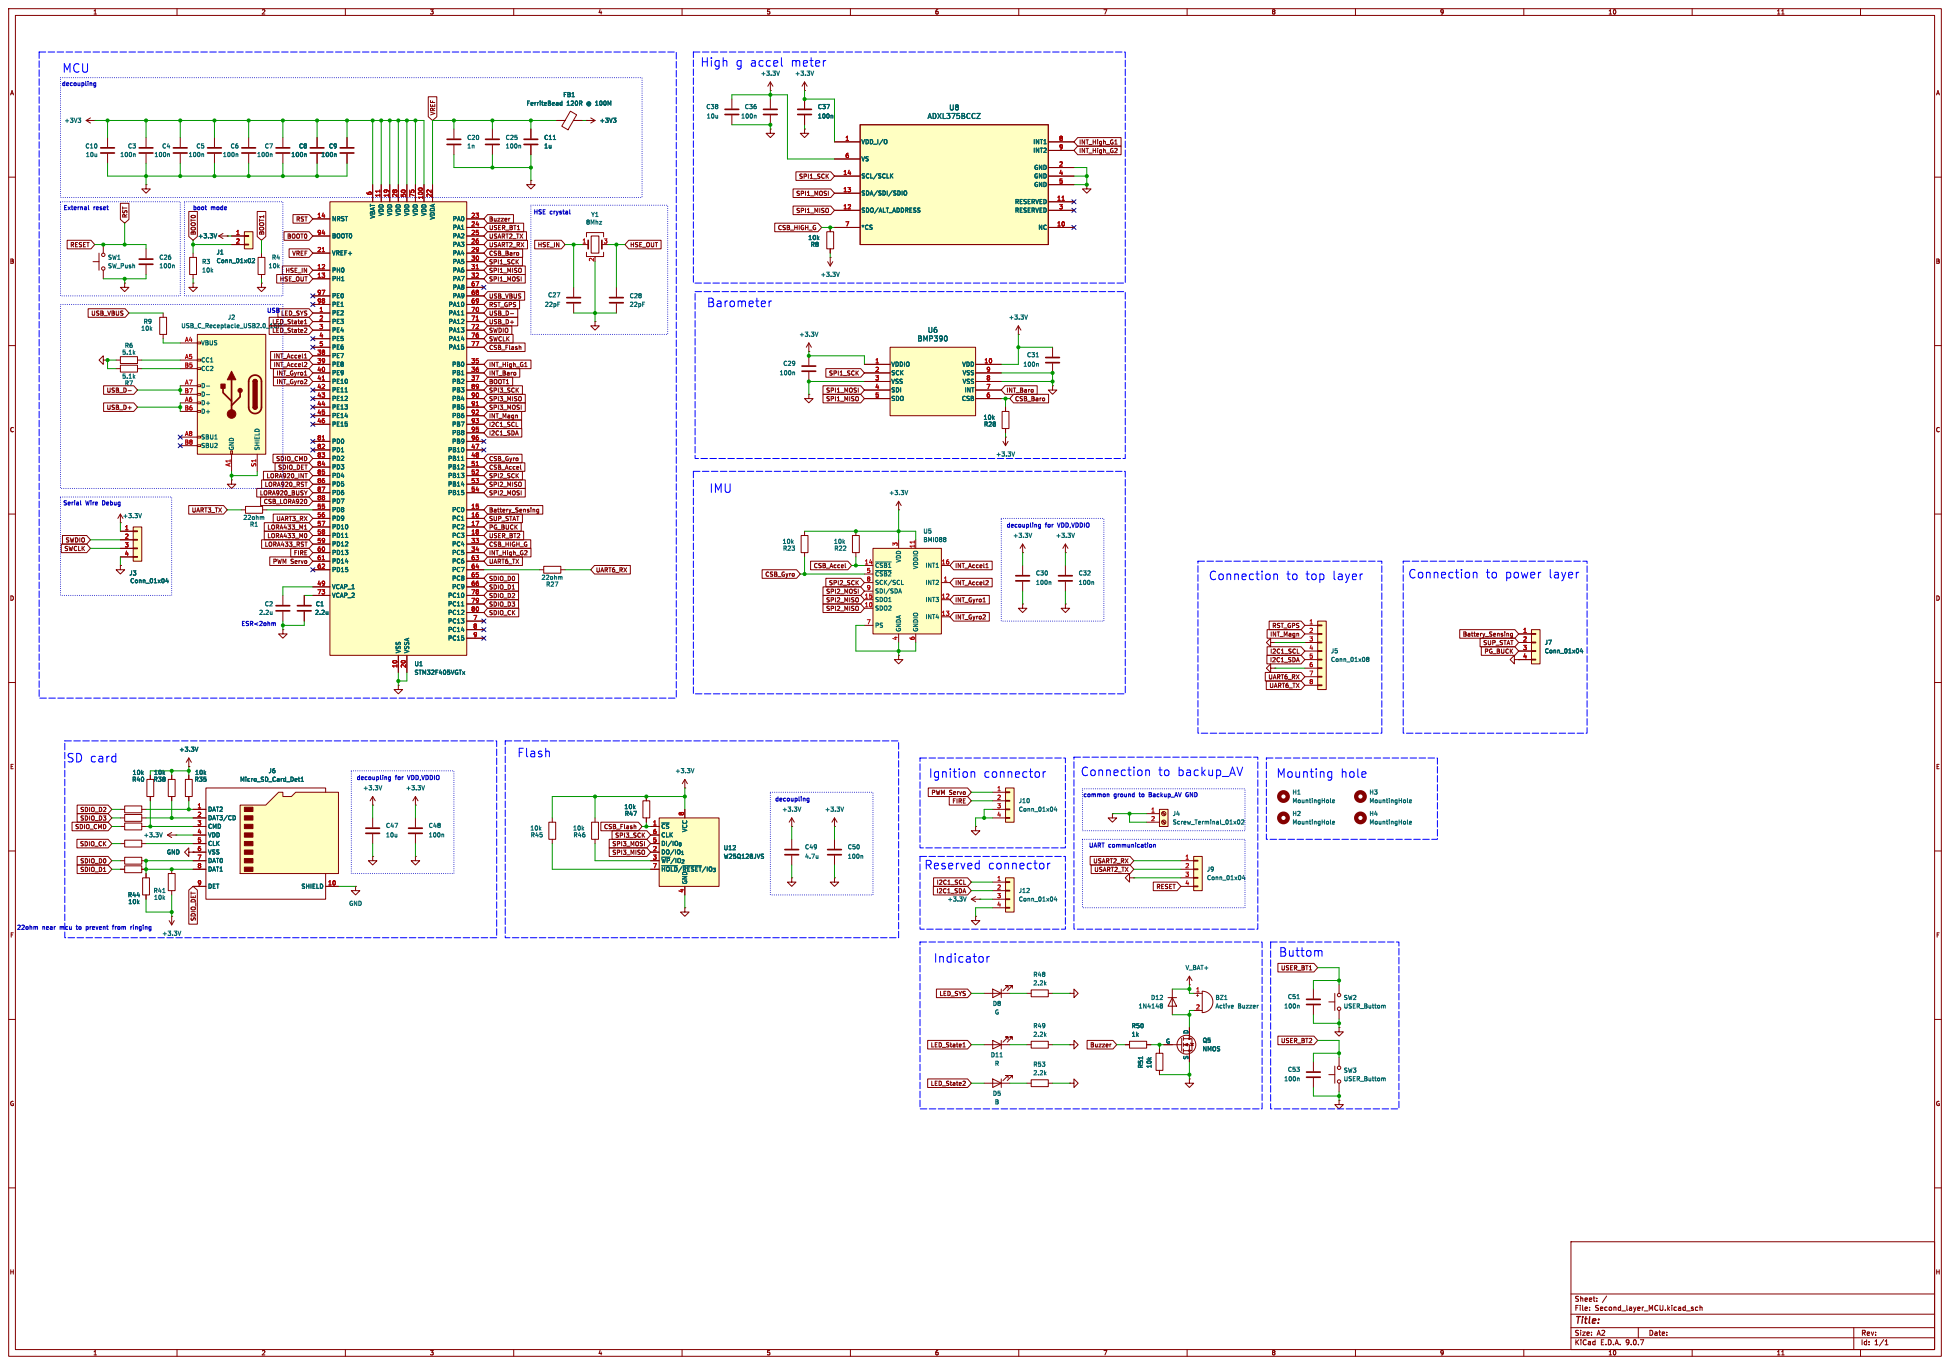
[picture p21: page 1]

6 VDD 11 VDD 19 VDD 28 VSS 10 VDD 50 VSSA 20 VDD 75 VDD 100 VDDA 22 PA0 23 PA1 24 PA2 25 PA3 26 PA4 29 PA5 30 PA6 31 PA7 32 PA8 67 PA9 68 PA10 69 PA11 70 PA12 71 PA13 72 PA14 76 PA15 77 PB0 35 PB1 36 PB2 37 PB3 89 PB4 90 PB5 91 PB6 92 PB7 93 PB8 95 PB9 96 PB10 47 PB11 48 PB12 51 PB13 52 PB14 53 PB15 54 PC0 15 PC1 16 PC2 17 PC3 18 PC4 33 PC5 34 PC6 63 PC7 64 PC8 65 PC9 66 PC10 78 PC11 79 PC12 80 PC13 7 PC14 8 PC15 9 U1STM32F405VGTx DAT2 1 DAT3/CD 2 CMD 3 VDD 4 CLK 5 VSS 6 DAT0 7 DAT1 8 DET 9 SHIELD 10

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

common ground to Backup_AV GND

22ohm near mcu to prevent from ringing

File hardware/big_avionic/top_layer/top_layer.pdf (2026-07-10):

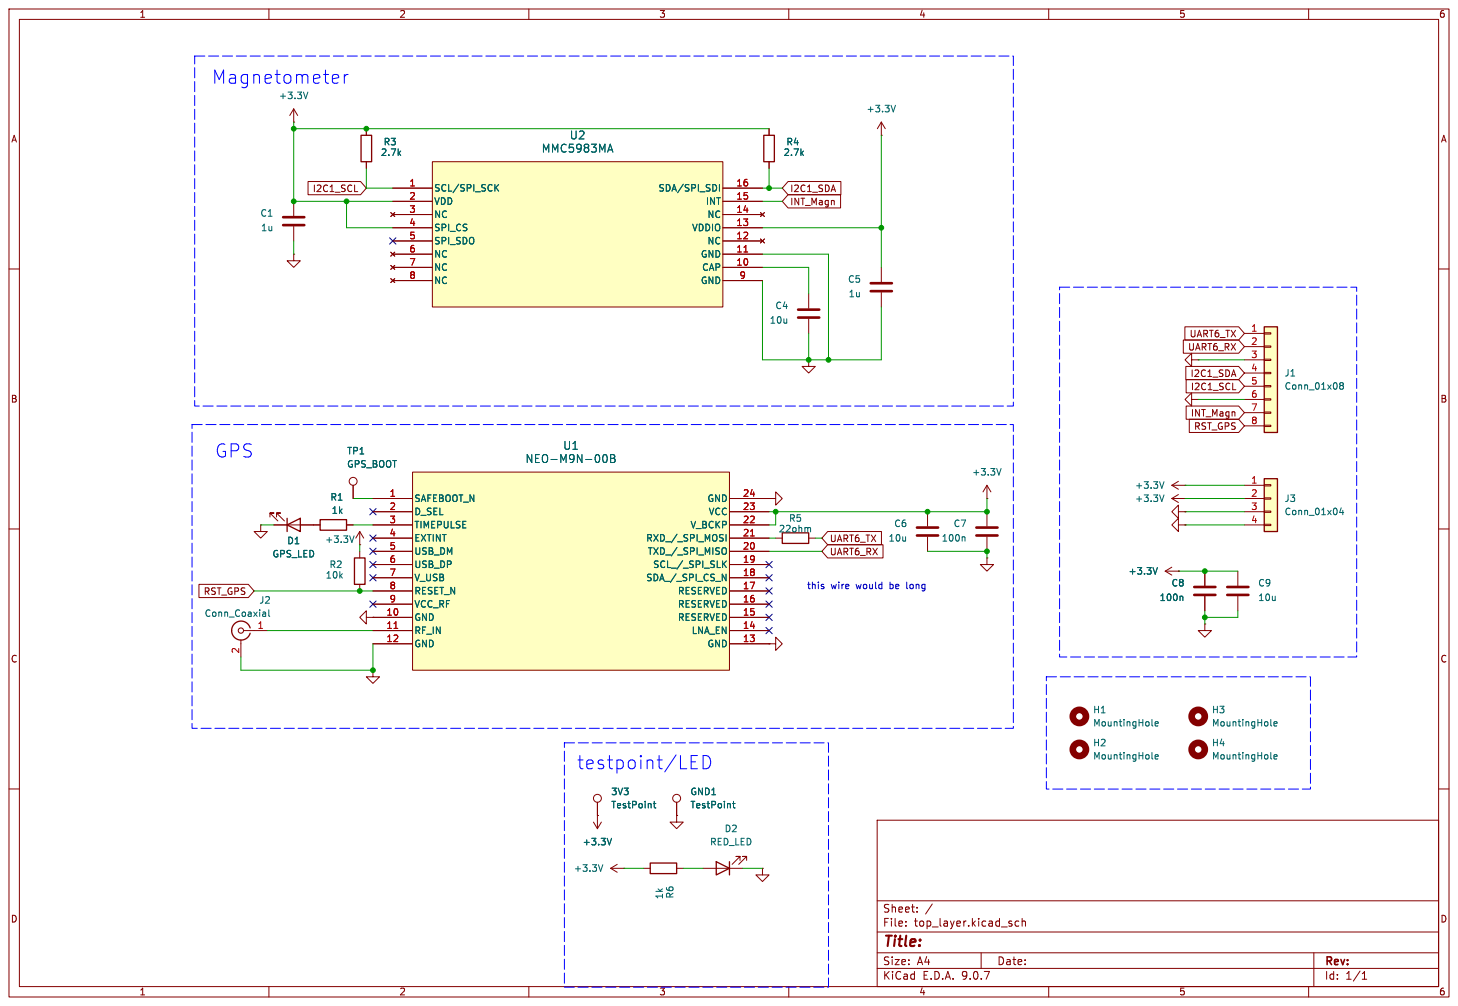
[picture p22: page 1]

this wire would be long

Id: 1/1 Title: File: top_layer.kicad_sch Sheet: /

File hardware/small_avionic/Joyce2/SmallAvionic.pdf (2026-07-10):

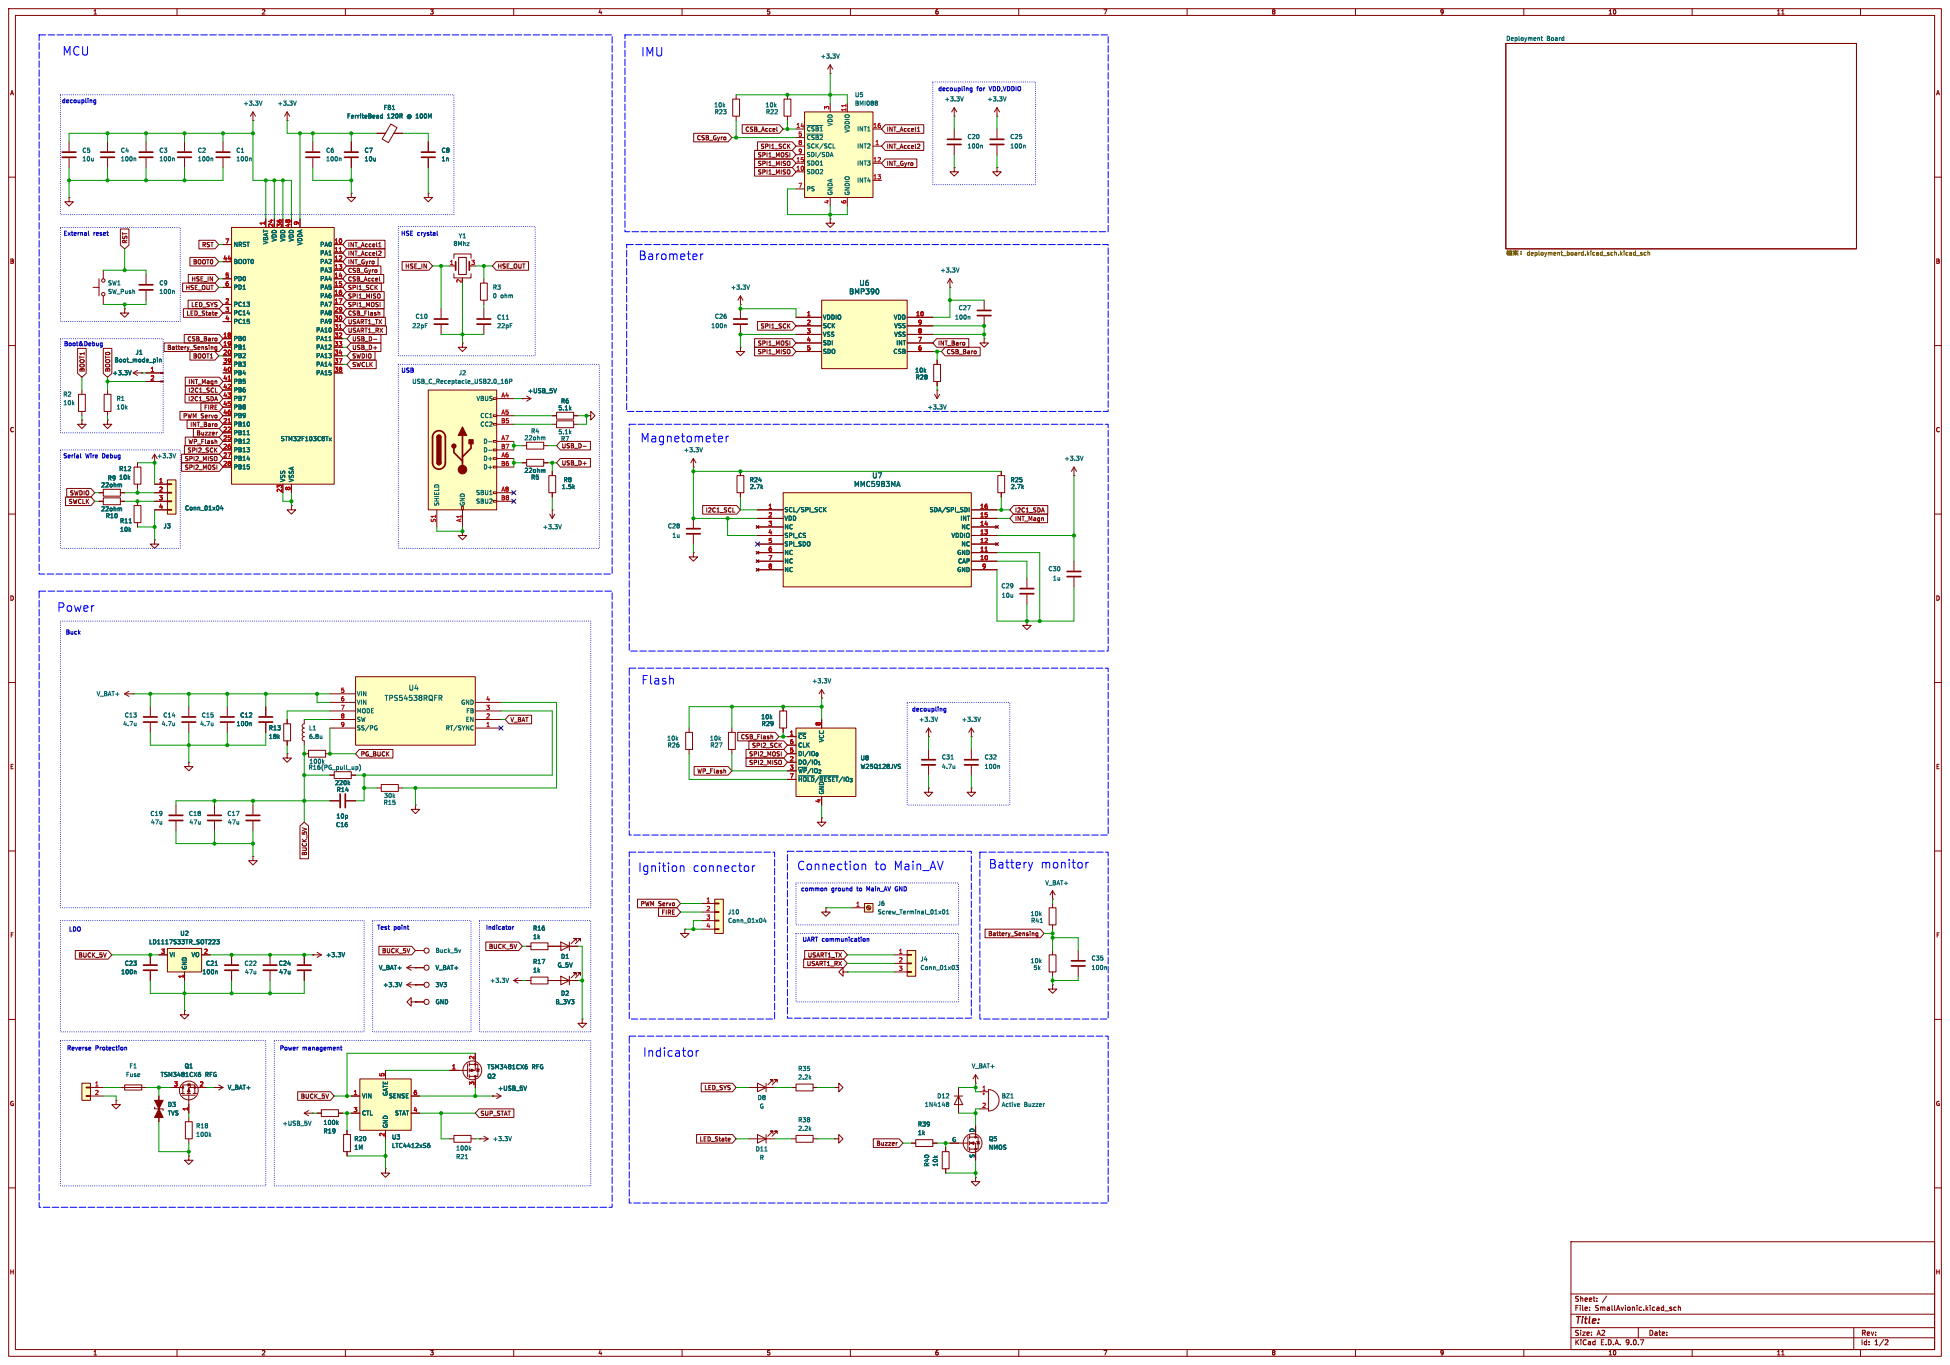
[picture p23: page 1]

common ground to Main_AV GND

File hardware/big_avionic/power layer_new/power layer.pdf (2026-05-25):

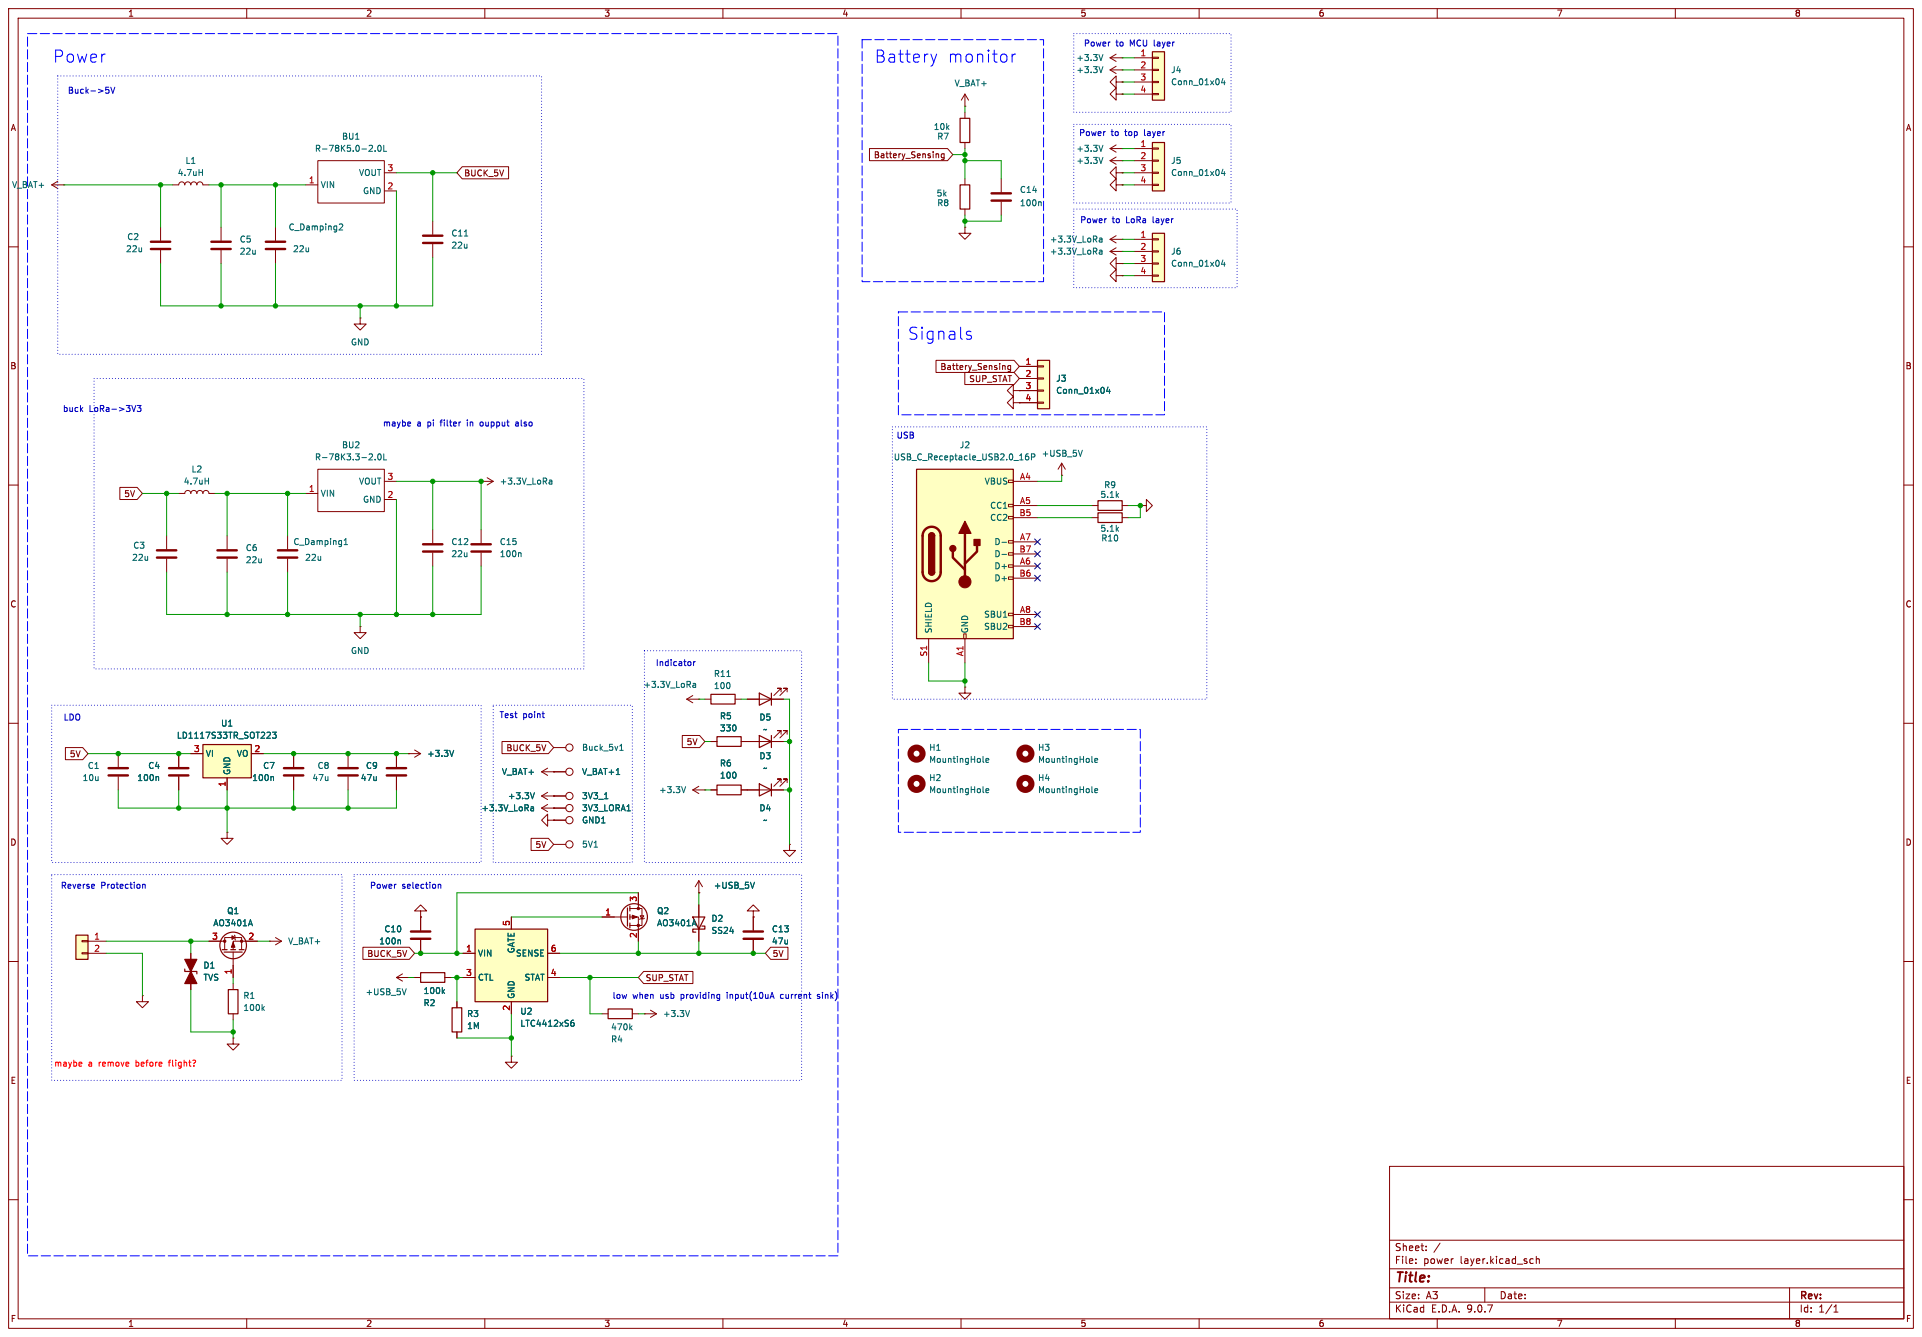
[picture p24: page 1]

Power to LoRa layer

maybe a remove before flight?

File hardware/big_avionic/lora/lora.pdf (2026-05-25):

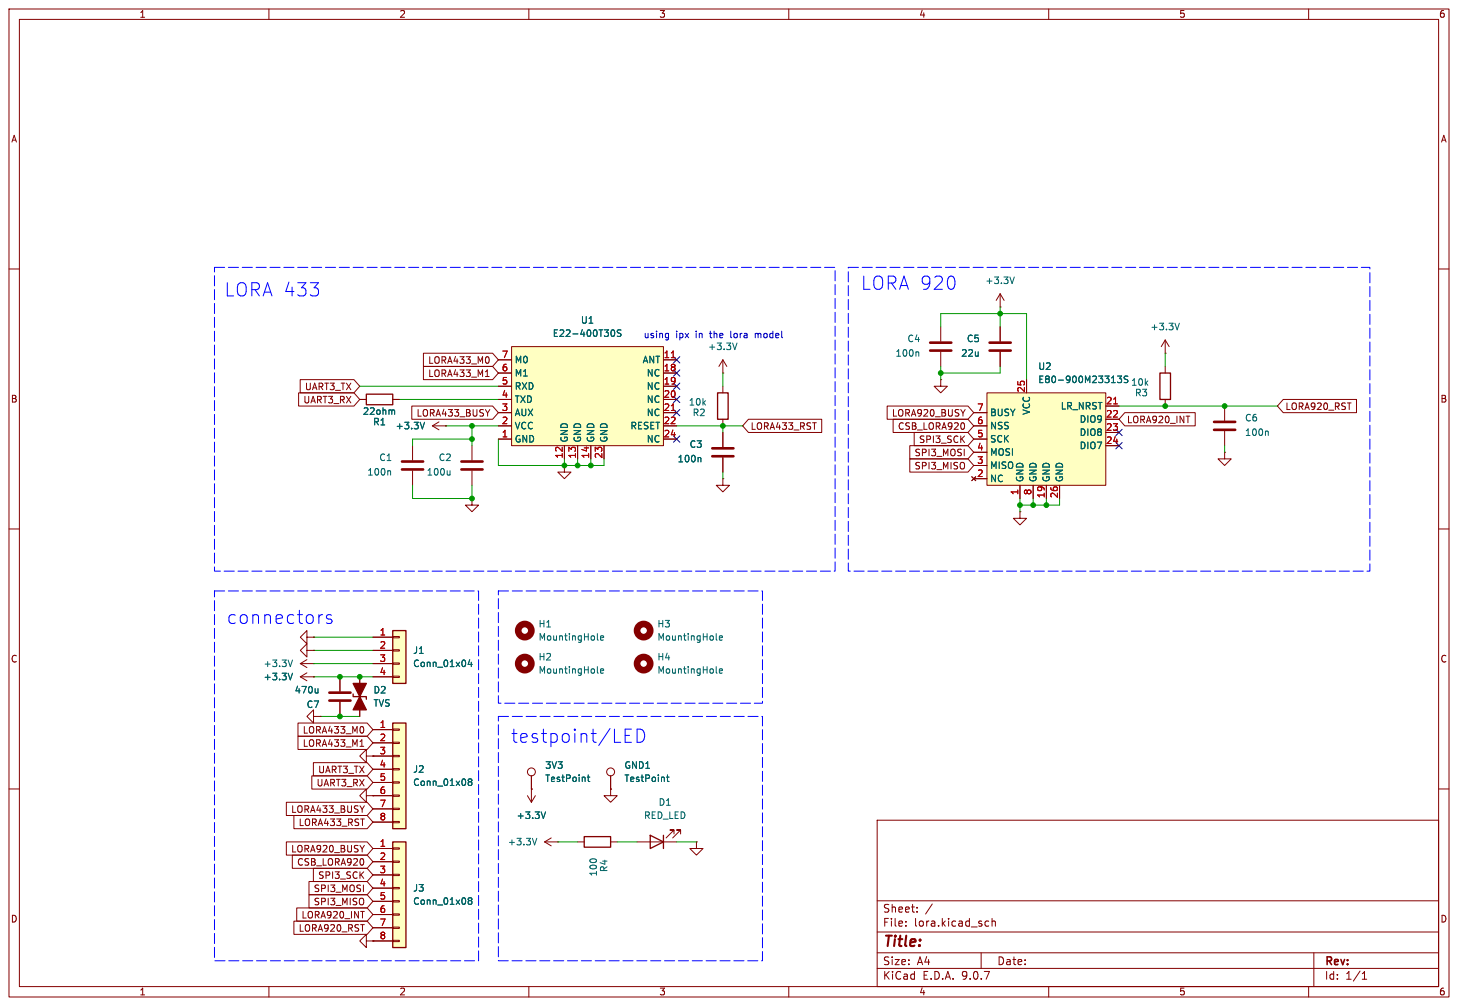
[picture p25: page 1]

using ipx in the lora model testpoint/LED

Id: 1/1 Title: File: lora.kicad_sch Sheet: /

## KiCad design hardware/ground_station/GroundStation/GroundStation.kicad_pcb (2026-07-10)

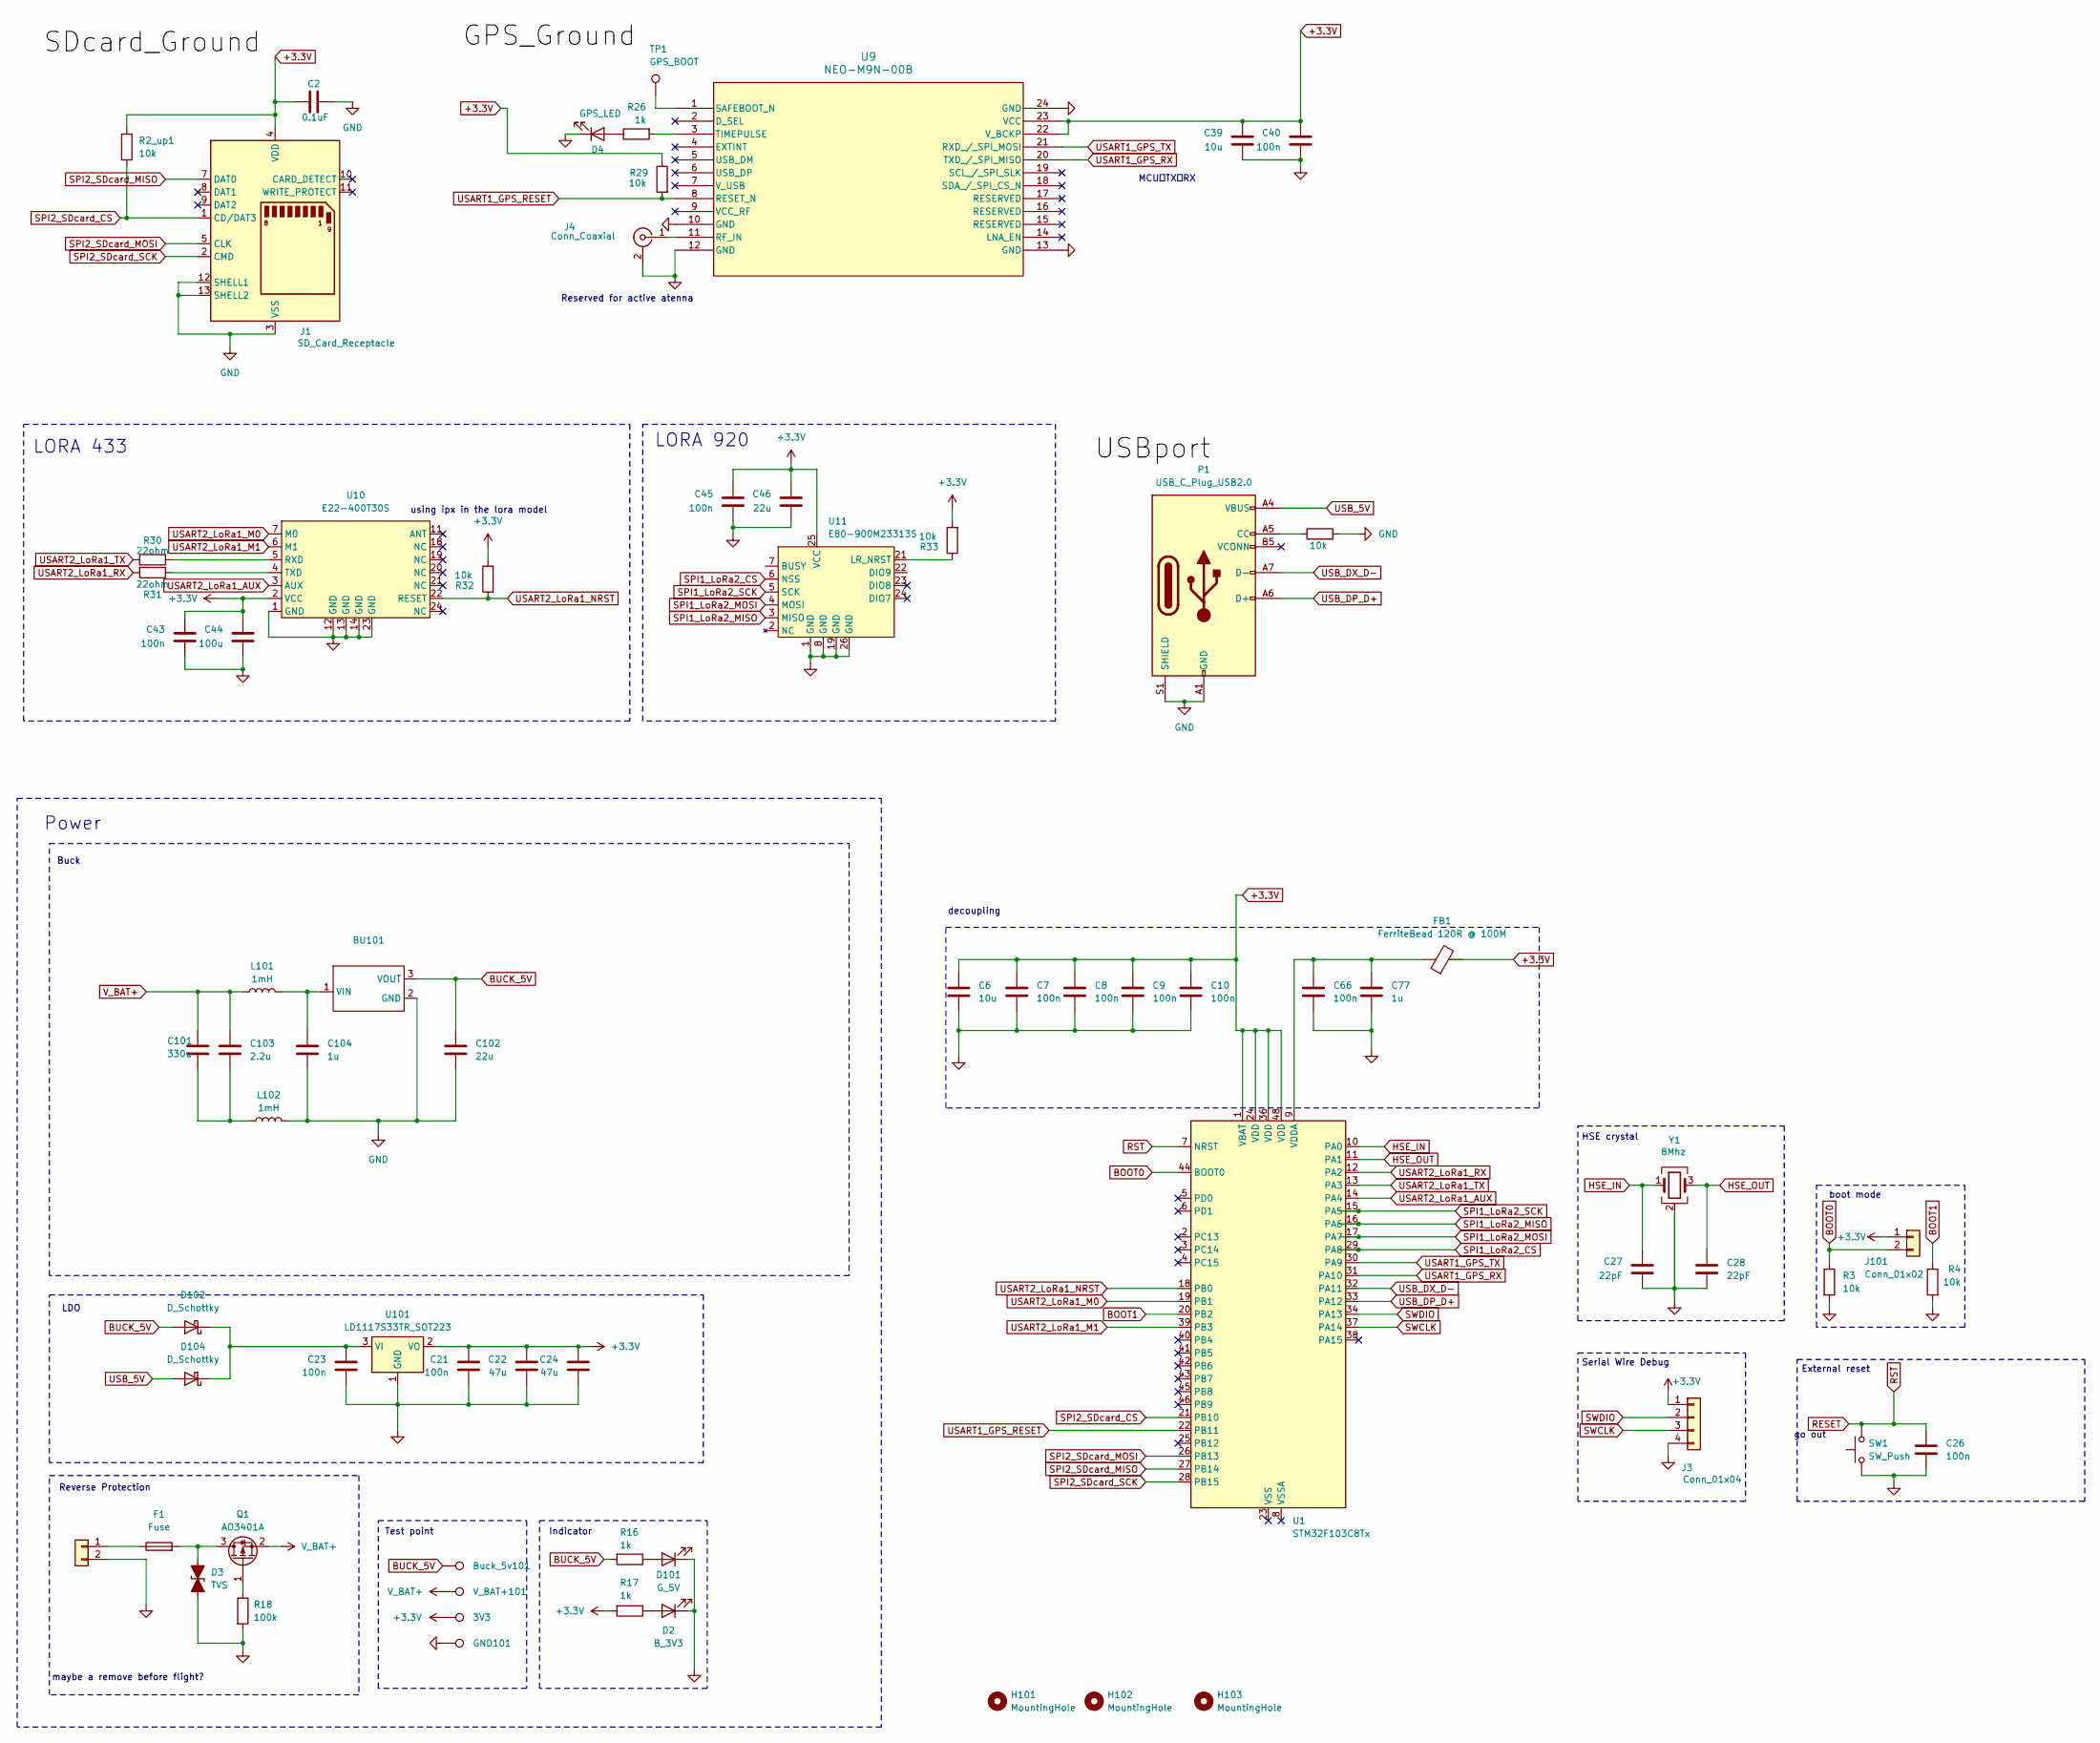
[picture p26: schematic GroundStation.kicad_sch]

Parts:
3V3: TestPoint; TestPoint_Pad_2.0x2.0mm
BU101: FanPinHeader_1x03_P2.54mm_Vertical
Buck_5v101: TestPoint; TestPoint_Pad_2.0x2.0mm
C2: 0.1uF; C_0805_2012Metric_Pad1.18x1.45mm_HandSolder
C6, C39: 10u; C_0805_2012Metric_Pad1.18x1.45mm_HandSolder
C7, C8, C9, C10, C21, C23, C40, C43, C45, C66: 100n; C_0805_2012Metric_Pad1.18x1.45mm_HandSolder
C22, C24: 47u; SMD3528
C26: 100n; C_0603_1608Metric_Pad1.08x0.95mm_HandSolder
C27, C28: 22pF; C_0603_1608Metric_Pad1.08x0.95mm_HandSolder
C44: 100u; C_0805_2012Metric_Pad1.18x1.45mm_HandSolder
C46, C102: 22u; C_0805_2012Metric_Pad1.18x1.45mm_HandSolder
C77, C104: 1u; C_0805_2012Metric_Pad1.18x1.45mm_HandSolder
C101: 330u; smd7343
C103: 2.2u; C_0805_2012Metric_Pad1.18x1.45mm_HandSolder
D2: B_3V3; LED_0805_2012Metric_Pad1.15x1.40mm_HandSolder
D3: TVS; D_SOD-123
D4: GPS_LED; LED_0805_2012Metric_Pad1.15x1.40mm_HandSolder
D101: G_5V; LED_0805_2012Metric_Pad1.15x1.40mm_HandSolder
D102, D104: D_Schottky; D_SMA
F1: Fuse; Fuse_1206_3216Metric
FB1: FerriteBead 120R @ 100M; L_2512_6332Metric
GND101: TestPoint; TestPoint_Pad_2.0x2.0mm
H101, H102, H103: MountingHole; MountingHole_3.2mm_M3
J1: SD_Card_Receptacle; SD_Kyocera_145638109511859+
J3: Conn_01x04; PinHeader_1x04_P2.54mm_Vertical
J4: Conn_Coaxial; U.FL_Hirose_U.FL-R-SMT-1_Vertical
J5: Conn_01x02; Molex_Micro-Fit_3.0_43650-0200_1x02_P3.00mm_Horizontal
J101: Conn_01x02; PinHeader_1x02_P2.54mm_Vertical
L101, L102: 1mH; L_0805_2012Metric_Pad1.05x1.20mm_HandSolder
P1: USB_C_Plug_USB2.0; USB_C_Receptacle_JAE_DX07S016JA1R1500
Q1: AO3401A; SOT-23
R2_up1, R3, R3_up1, R4, R29, R32, R33: 10k; R_0805_2012Metric_Pad1.20x1.40mm_HandSolder
R16, R17, R26: 1k; R_0805_2012Metric_Pad1.20x1.40mm_HandSolder
R18: 100k; R_0805_2012Metric_Pad1.20x1.40mm_HandSolder
R30, R31: 22ohm; R_0805_2012Metric_Pad1.20x1.40mm_HandSolder
SW1: SW_Push; SW_PUSH_6mm_H4.3mm
TP1: GPS_BOOT; TestPoint_Pad_D1.0mm
U1: STM32F103C8Tx; LQFP-48_7x7mm_P0.5mm
U9: NEO-M9N-00B; ublox_NEO
U10: E22-400T30S; e22-400t30s_Package
U11: E80-900M23313S; E80-900M2213S
U101: LD1117S33TR_SOT223; SOT-223-3_TabPin2
V_BAT+101: TestPoint; TestPoint_Pad_2.0x2.0mm
Y1: 8Mhz; Crystal_SMD_5032-4Pin_5.0x3.2mm

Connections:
+3.3V: 3V3.1, C2.1, C6.1, C7.1, C8.1, C9.1, C10.1, C21.1, C22.1, C24.1, C39.1, C40.1, C43.1, C44.1, C45.1, C46.1, J1.4 (VDD), J3.1, J101.1, R2_up1.1, R17.2, R29.1, R32.2, R33.2, U1.1 (VBAT), U1.24 (VDD), U1.36 (VDD), U1.48 (VDD), U9.22 (V_BCKP), U9.23 (VCC), U10.2 (VCC), U11.25 (VCC), U101.2 (VO)
BOOT0: J101.2, R3.1, U1.44 (BOOT0)
BOOT1: R4.1, U1.20 (PB2)
BUCK_5V: BU101.3 (VOUT), Buck_5v101.1, C102.1, D102.2 (A), R16.2
GND: BU101.2 (GND), C2.2, C6.2, C7.2, C8.2, C9.2, C10.2, C21.2, C22.2, C23.2, C24.2, C26.2, C27.2, C28.2, C39.2, C40.2, C43.2, C44.2, C45.2, C46.2, C66.2, C77.2, C102.2, C104.2, D2.1 (K), D3.1 (A1), D4.1 (K), D101.1 (K), GND101.1, J1.3 (VSS), J1.6 (VSS), J1.12 (SHELL1), J1.13 (SHELL2), J3.4, J4.2 (Ext), J5.2, L102.2, P1.A1 (GND), P1.A12 (GND), P1.B1 (GND), P1.B12 (GND), P1.S1 (SHIELD), R3.2, R3_up1.2, R4.2, R18.2, SW1.1, U9.10 (GND), U9.12 (GND), U9.13 (GND), U9.24 (GND), U10.1 (GND), U10.12 (GND), U10.13 (GND), U10.14 (GND), U10.23 (GND), U11.1 (GND), U11.8 (GND), U11.19 (GND), U11.26 (GND), U101.1 (GND), Y1.2 (G), Y1.4 (G); also elsewhere on the board
HSE_IN: C27.1, U1.10 (PA0), Y1.1
HSE_OUT: C28.1, U1.11 (PA1), Y1.3
unnamed: BU101.1 (VIN), C104.1, L101.2
unnamed: C101.2, C103.2, L102.1
unnamed: D2.2 (A), R17.1
unnamed: D3.2 (A2), F1.2, Q1.3 (D)
unnamed: D4.2 (A), R26.1
unnamed: D101.2 (A), R16.1
unnamed: C23.1, D102.1 (K), D104.1 (K), U101.3 (VI)
unnamed: J4.1 (In), U9.11 (RF_IN)
unnamed: F1.1, J5.1
unnamed: P1.A5 (CC), R3_up1.1
unnamed: Q1.1 (G), R18.1
unnamed: C66.1, C77.1, FB1.1, U1.9 (VDDA)
unnamed: TP1.1, U9.1 (SAFEBOOT_N)
unnamed: R26.2, U9.3 (TIMEPULSE)
unnamed: R30.1, U10.5 (RXD)
unnamed: R31.1, U10.4 (TXD)
unnamed: R33.1, U11.21 (LR_NRST)
RESET: C26.1, SW1.2, U1.7 (NRST); also elsewhere on the board
SPI1_LoRa2_CS: U1.29 (PA8), U11.6 (NSS)
SPI1_LoRa2_MISO: U1.16 (PA6), U11.3 (MISO)
SPI1_LoRa2_MOSI: U1.17 (PA7), U11.4 (MOSI)
SPI1_LoRa2_SCK: U1.15 (PA5), U11.5 (SCK)
SPI2_SDcard_CS: J1.1 (CD/DAT3), R2_up1.2, U1.21 (PB10)
SPI2_SDcard_MISO: J1.7 (DAT0), U1.27 (PB14)
SPI2_SDcard_MOSI: J1.5 (CLK), U1.26 (PB13)
SPI2_SDcard_SCK: J1.2 (CMD), U1.28 (PB15)
SWCLK: J3.3, U1.37 (PA14)
SWDIO: J3.2, U1.34 (PA13)
USART1_GPS_RESET: R29.2, U1.22 (PB11), U9.8 (RESET_N)
USART1_GPS_RX: U1.31 (PA10), U9.20 (TXD_/_SPI_MISO)
USART1_GPS_TX: U1.30 (PA9), U9.21 (RXD_/_SPI_MOSI)
USART2_LoRa1_AUX: U1.14 (PA4), U10.3 (AUX)
USART2_LoRa1_M0: U1.19 (PB1), U10.7 (M0)
USART2_LoRa1_M1: U1.39 (PB3), U10.6 (M1)
USART2_LoRa1_NRST: R32.1, U1.18 (PB0), U10.22 (RESET)
USART2_LoRa1_RX: R31.2, U1.12 (PA2)
USART2_LoRa1_TX: R30.2, U1.13 (PA3)
USB_5V: D104.2 (A), P1.A4 (VBUS), P1.A9 (VBUS), P1.B4 (VBUS), P1.B9 (VBUS)
USB_DP_D+: P1.A6 (D+), U1.33 (PA12)
USB_DX_D-: P1.A7 (D-), U1.32 (PA11)
V_BAT+: C101.1, C103.1, L101.1, Q1.2 (S), V_BAT+101.1

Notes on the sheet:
using ipx in the lora model
LORA 433
External reset
boot mode
LORA 920
HSE crystal
Reverse Protection
Buck
decoupling
LDO
maybe a remove before flight?
Test point
Reserved for active atenna
Power
Serial Wire Debug
MCU的TX跟RX
go out
Indicator

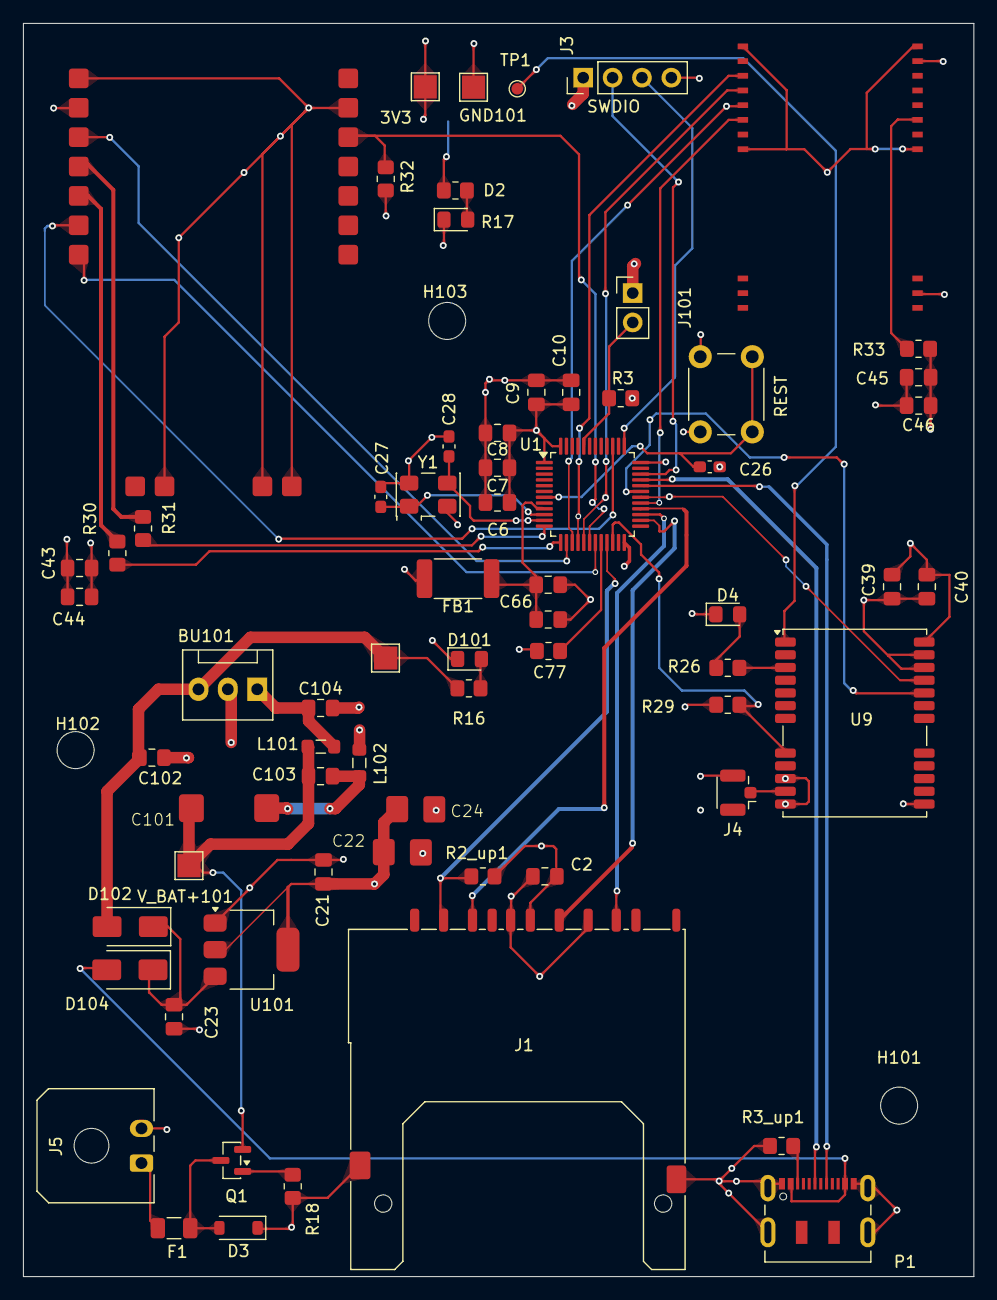
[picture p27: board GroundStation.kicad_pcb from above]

Board: 4 copper layers, 82.2 x 108.3 mm, 71 parts (0 on the bottom side), 48 nets.

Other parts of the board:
REST: SW_Push; SW_PUSH_6mm_H4.3mm

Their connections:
GND: REST.1; also elsewhere on the board
RESET: REST.2; also elsewhere on the board

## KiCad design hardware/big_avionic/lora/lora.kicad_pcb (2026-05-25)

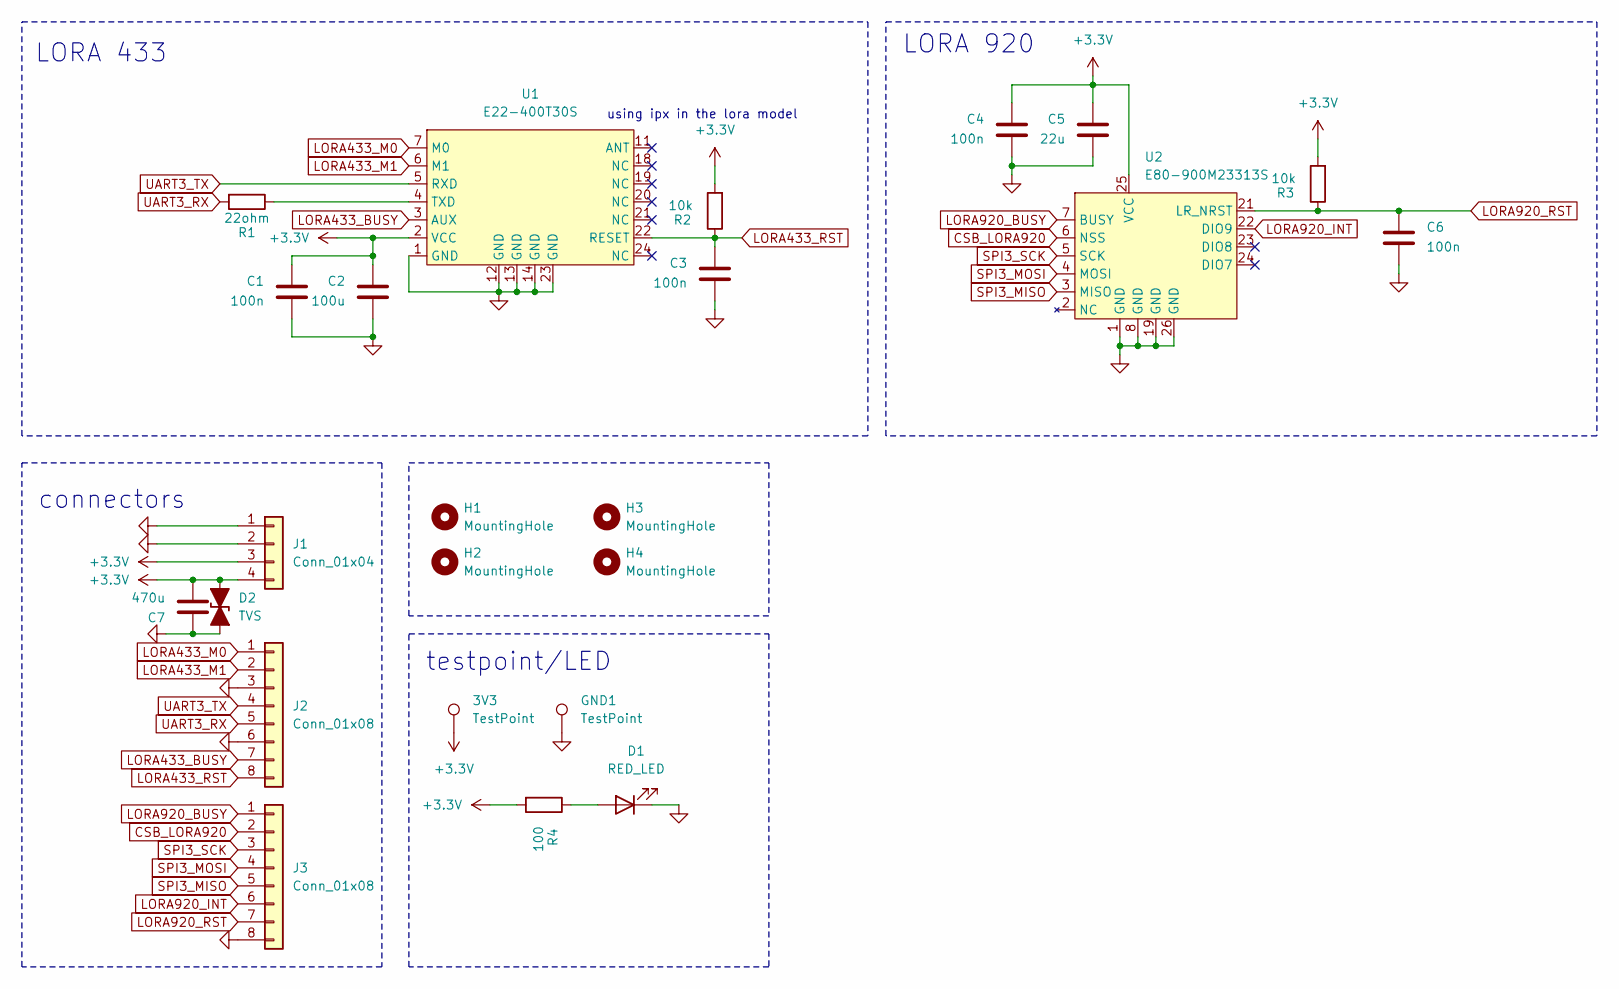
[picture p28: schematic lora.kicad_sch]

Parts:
3V3: TestPoint; TestPoint_Pad_D1.0mm
C1, C3, C4, C6: 100n; C_0805_2012Metric_Pad1.18x1.45mm_HandSolder
C2: 100u; CP_EIA-7343-31_Kemet-D_HandSolder
C5: 22u; C_1206_3216Metric_Pad1.33x1.80mm_HandSolder
C7: 470u; CP_EIA-7343-43_Kemet-X_HandSolder
D1: RED_LED; LED_0805_2012Metric_Pad1.15x1.40mm_HandSolder
D2: TVS; D_SMA
GND1: TestPoint; TestPoint_Pad_D1.0mm
H1, H2, H3, H4: MountingHole; MountingHole_3.2mm_M3_DIN965_Pad
J1: Conn_01x04; JST_GH_SM04B-GHS-TB_1x04-1MP_P1.25mm_Horizontal
J2, J3: Conn_01x08; JST_GH_SM08B-GHS-TB_1x08-1MP_P1.25mm_Horizontal
R1: 22ohm; R_0805_2012Metric_Pad1.20x1.40mm_HandSolder
R2, R3: 10k; R_0805_2012Metric_Pad1.20x1.40mm_HandSolder
R4: 100; R_0805_2012Metric_Pad1.20x1.40mm_HandSolder
U1: E22-400T30S; XCVR_E22-900T30S
U2: E80-900M23313S; E80-xxxM2213S

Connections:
+3.3V: 3V3.1, C1.1, C2.1, C4.1, C5.1, C7.2, D2.2 (A2), J1.3, J1.4, R2.2, R3.2, R4.2, U1.2 (VCC), U2.25 (VCC)
CSB_LORA920: J3.2, U2.6 (NSS)
GND: C1.2, C2.2, C3.2, C4.2, C5.2, C6.2, C7.1, D1.1 (K), D2.1 (A1), GND1.1, J1.1, J1.2, J2.3, J2.6, J3.8, U1.1 (GND), U1.12 (GND), U1.13 (GND), U1.14 (GND), U1.23 (GND), U2.1 (GND), U2.8 (GND), U2.19 (GND), U2.26 (GND)
LORA433_BUSY: J2.7, U1.3 (AUX)
LORA433_M0: J2.1, U1.7 (M0)
LORA433_M1: J2.2, U1.6 (M1)
LORA433_RST: C3.1, J2.8, R2.1, U1.22 (RESET)
LORA920_BUSY: J3.1, U2.7 (BUSY)
LORA920_INT: J3.6, U2.22 (DIO9)
LORA920_RST: C6.1, J3.7, R3.1, U2.21 (LR_NRST)
unnamed: D1.2 (A), R4.1
unnamed: R1.1, U1.4 (TXD)
SPI3_MISO: J3.5, U2.3 (MISO)
SPI3_MOSI: J3.4, U2.4 (MOSI)
SPI3_SCK: J3.3, U2.5 (SCK)
UART3_RX: J2.5, R1.2
UART3_TX: J2.4, U1.5 (RXD)

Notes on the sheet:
LORA 920
testpoint/LED
using ipx in the lora model
connectors
LORA 433

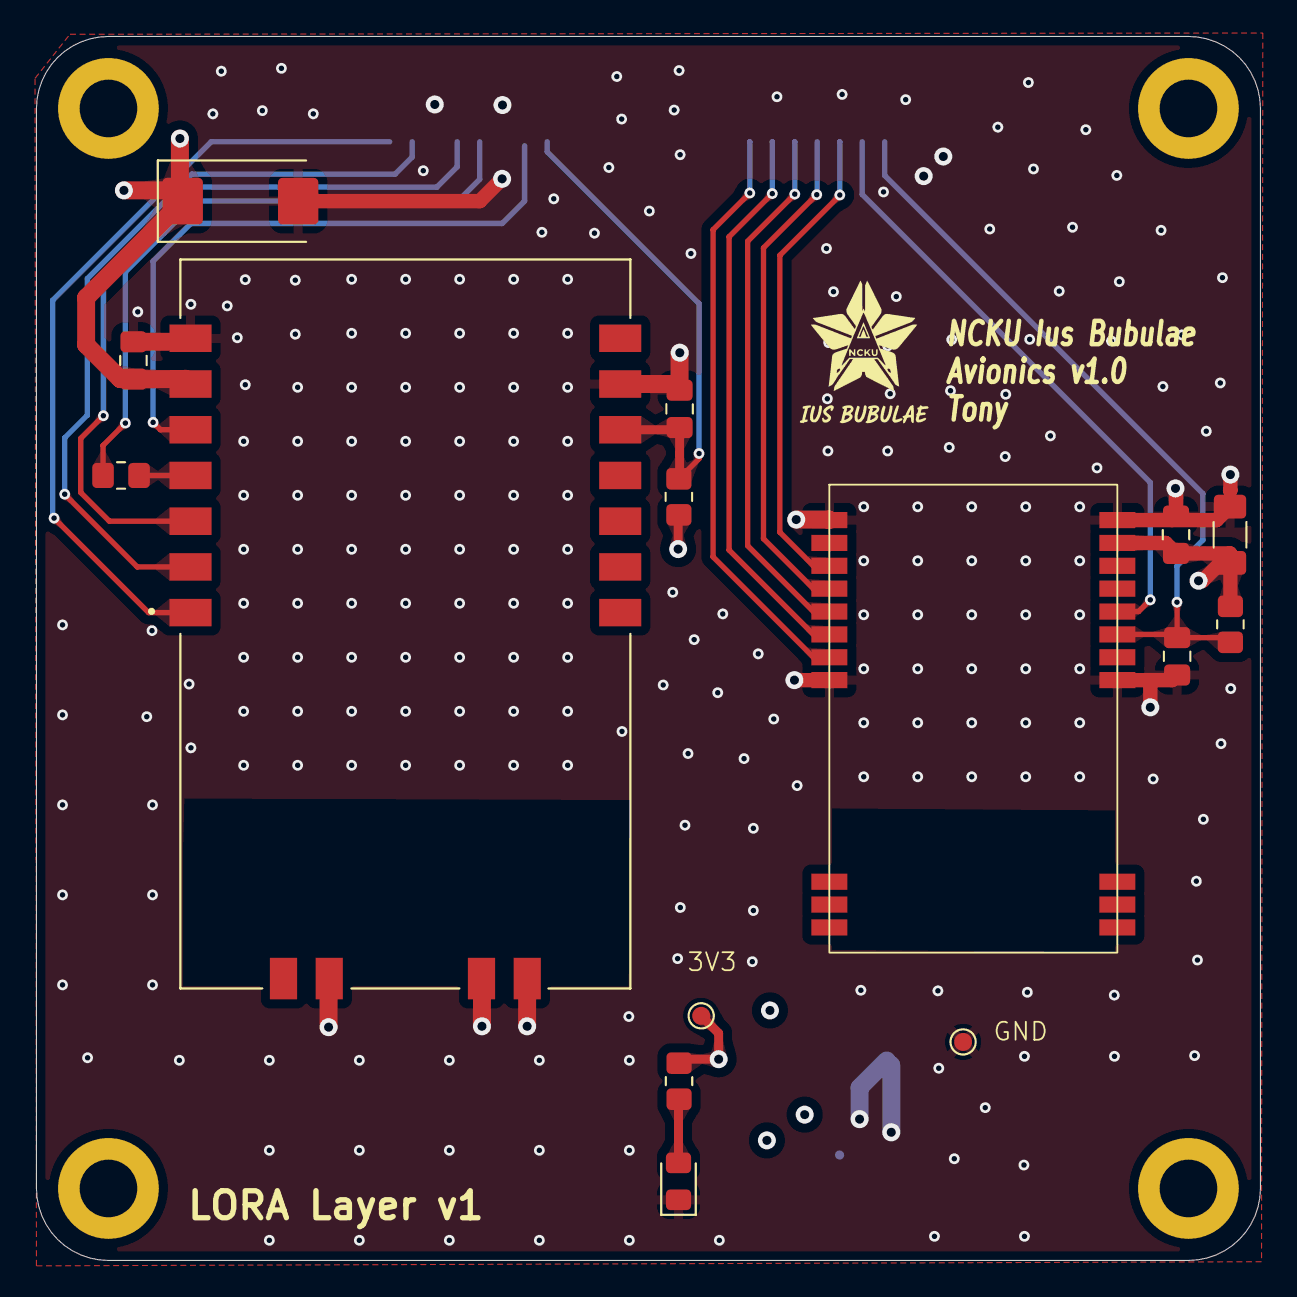
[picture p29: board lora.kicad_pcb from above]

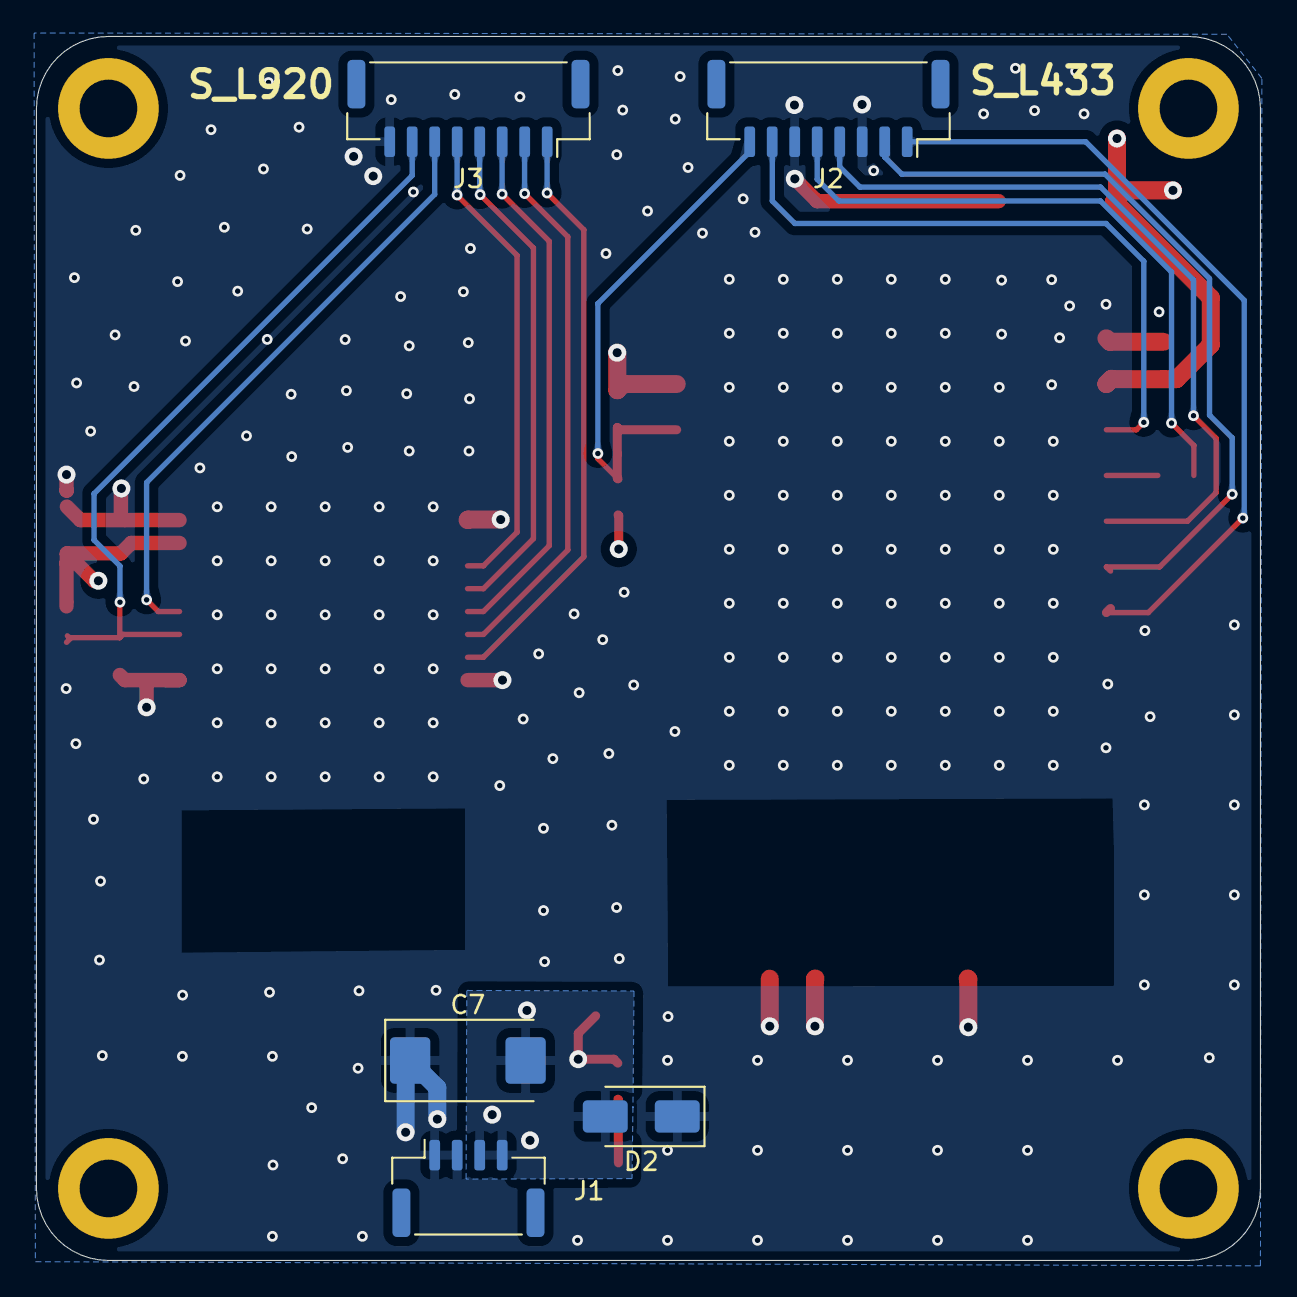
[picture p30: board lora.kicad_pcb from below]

Board: 4 copper layers, 68.0 x 68.0 mm, 24 parts (5 on the bottom side), 17 nets.

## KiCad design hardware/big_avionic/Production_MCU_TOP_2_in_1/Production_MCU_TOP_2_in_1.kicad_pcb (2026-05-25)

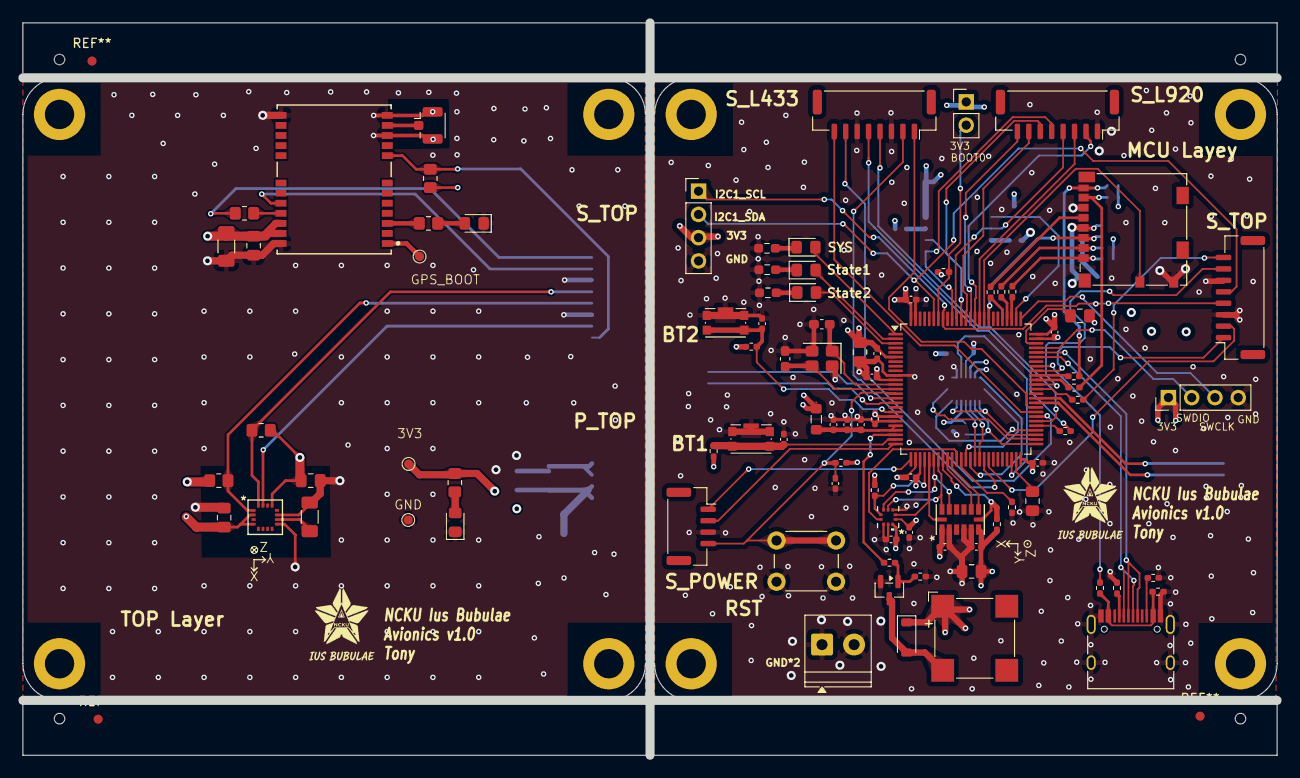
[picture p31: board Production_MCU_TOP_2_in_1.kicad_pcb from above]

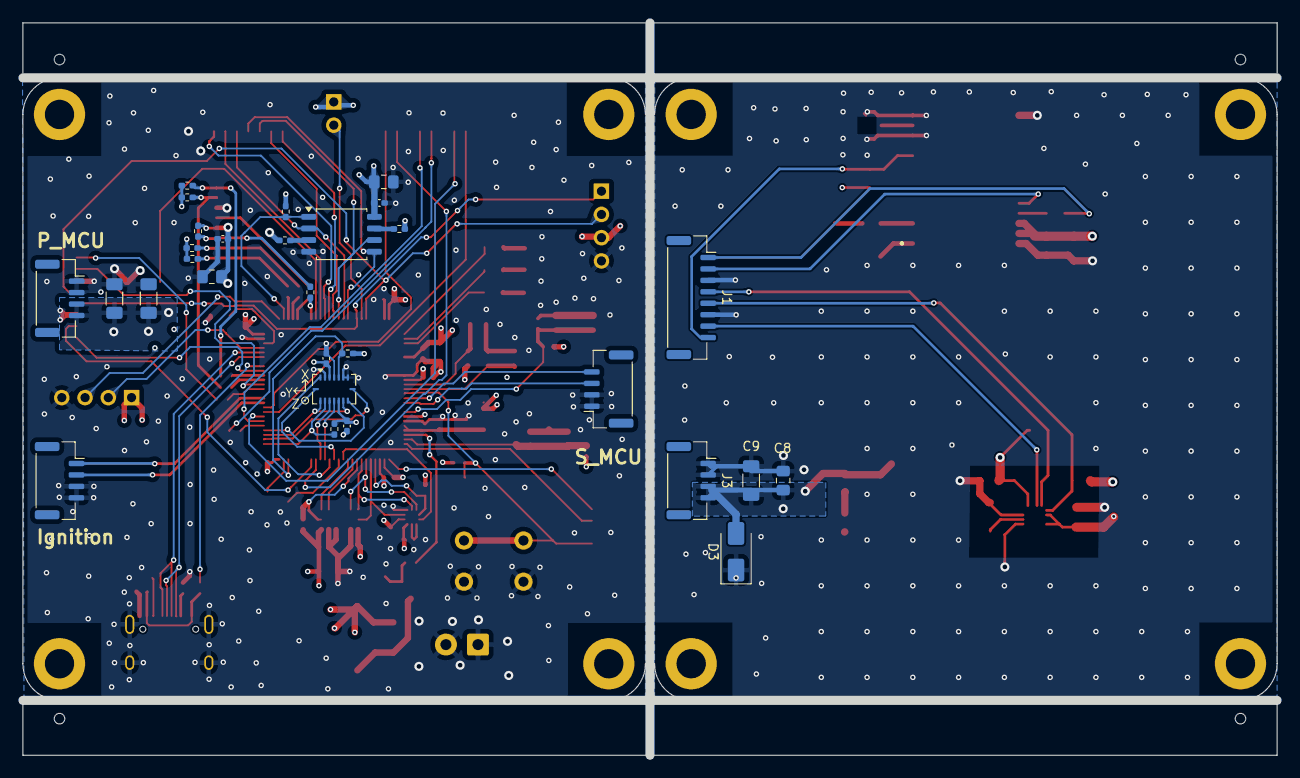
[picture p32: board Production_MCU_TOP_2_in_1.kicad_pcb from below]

Board: 4 copper layers, 137.0 x 80.0 mm, 126 parts (29 on the bottom side), 96 nets.

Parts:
3V3: TestPoint; TestPoint_Pad_D1.0mm
BZ1: Active Buzzer; MagneticBuzzer_CUI_CMT-8504-100-SMT
C1, C5#2: 1u; C_0805_2012Metric_Pad1.18x1.45mm_HandSolder
C1#2, C12, C19: 10u; C_0805_2012Metric_Pad1.18x1.45mm_HandSolder
C2, C3, C4#2, C5, C6#2, C7#2, C10, C11, C13, C15, C20, C22, C23, C24, C25, C26, C27, C28, C29: 100n; C_0402_1005Metric_Pad0.74x0.62mm_HandSolder
C4, C6, C9#2: 10u; C_1206_3216Metric_Pad1.33x1.80mm_HandSolder
C7, C8#2: 100n; C_0805_2012Metric_Pad1.18x1.45mm_HandSolder
C8, C9: 2.2u; C_0805_2012Metric_Pad1.18x1.45mm_HandSolder
C14: 1n; C_0402_1005Metric_Pad0.74x0.62mm_HandSolder
C16: 1u; C_0402_1005Metric_Pad0.74x0.62mm_HandSolder
C17, C18: 10pF; C_0603_1608Metric_Pad1.08x0.95mm_HandSolder
C21: 4.7u; C_0805_2012Metric_Pad1.18x1.45mm_HandSolder
C30, C31: 22u; C_1206_3216Metric_Pad1.33x1.80mm_HandSolder
D1: GPS_LED; LED_0805_2012Metric_Pad1.15x1.40mm_HandSolder
D1#2: Y; LED_0805_2012Metric_Pad1.15x1.40mm_HandSolder
D2: G; LED_0805_2012Metric_Pad1.15x1.40mm_HandSolder
D2#2: RED_LED; LED_0805_2012Metric_Pad1.15x1.40mm_HandSolder
D3: W; LED_0805_2012Metric_Pad1.15x1.40mm_HandSolder
D3#2: TVS; D_SMA
D4: 1N4148; D_SOD-123
FB1: FerriteBead 120R @ 100M; L_0805_2012Metric_Pad1.05x1.20mm_HandSolder
GND1: TestPoint; TestPoint_Pad_D1.0mm
H1, H1#2, H2, H2#2, H3, H3#2, H4, H4#2: MountingHole; MountingHole_3.2mm_M3_DIN965_Pad
J1, J6: Conn_01x04; PinHeader_1x04_P2.54mm_Vertical
J1#2, J9, J13, J14: Conn_01x08; JST_GH_SM08B-GHS-TB_1x08-1MP_P1.25mm_Horizontal
J2: USB_C_Receptacle_USB2.0_16P; USB_C_Receptacle_HRO_TYPE-C-31-M-12
J2#2: Conn_Coaxial; U.FL_Hirose_U.FL-R-SMT-1_Vertical
J3: Conn_01x02; PinHeader_1x02_P2.54mm_Vertical
J3#2, J5, J8, J10, J11: Conn_01x04; JST_GH_SM04B-GHS-TB_1x04-1MP_P1.25mm_Horizontal
J4: Micro_SD_Card_Det1; microSD_HC_Molex_104031-0811
J7: Screw_Terminal_01x02; TerminalBlock_Phoenix_PT-1,5-2-3.5-H_1x02_P3.50mm_Horizontal
Q2: AO3400A; SOT-23
R1, R6: 1k; R_0805_2012Metric_Pad1.20x1.40mm_HandSolder
R1#2: 100k; R_0402_1005Metric_Pad0.72x0.64mm_HandSolder
R2, R3: 5.1k; R_0402_1005Metric_Pad0.72x0.64mm_HandSolder
R2#2: 10k; R_0805_2012Metric_Pad1.20x1.40mm_HandSolder
R3#2, R4: 2.7k; R_0805_2012Metric_Pad1.20x1.40mm_HandSolder
R4#2, R5#2: 4.7k; R_0402_1005Metric_Pad0.72x0.64mm_HandSolder
R5: 22ohm; R_0805_2012Metric_Pad1.20x1.40mm_HandSolder
R6#2, R7, R8, R9, R17, R19, R32, R33: 22ohm; R_0402_1005Metric_Pad0.72x0.64mm_HandSolder
R10, R11, R12, R13, R14, R15, R16, R18, R20, R21, R22, R23, R24, R25, R26, R31, R35: 10k; R_0402_1005Metric_Pad0.72x0.64mm_HandSolder
R27: 220; R_0603_1608Metric_Pad0.98x0.95mm_HandSolder
R28, R29: 100; R_0603_1608Metric_Pad0.98x0.95mm_HandSolder
R30: 1k; R_0402_1005Metric_Pad0.72x0.64mm_HandSolder
SW1: SW_Push; SW_PUSH_6mm_H4.3mm
SW2, SW3: SW_Push_Shielded; SW_Push_1P1T-SH_NO_CK_KMR2xxG
TP1: GPS_BOOT; TestPoint_Pad_D1.0mm
U1: STM32F405VGTx; LQFP-100_14x14mm_P0.5mm
U1#2: NEO-M9N-00B; SMT_9N-00B_UBL
U2: MMC5983MA; MMC5983MA_MEM
U2#2: W25Q128JVS; SOIC-8_5.3x5.3mm_P1.27mm
U3: ADXL375BCCZ; LGA_CC-14-1_ADI-L
U4: BMP388/390; 10LGA_2X2X0p75_BOS-M
U5: BMI088; Bosch_LGA-16_4.5x3mm_P0.5mm_LayoutBorder7x1y_ClockwisePinNu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
Y1: FA-238 16Mhz; Crystal_SMD_SeikoEpson_FA238-4Pin_3.2x2.5mm

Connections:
+3.3V: 3V3.1, BZ1.1 (+), C1.1, C1#2.1, C2.1, C4#2.1, C5.1, C5#2.1, C6.1, C6#2.1, C7.1, C7#2.1, C8#2.1, C9#2.1, C10.1, C11.1, C12.1, C13.1, C19.1, C20.1, C21.1, C22.1, C23.1, C24.1, C25.1, C26.1, C27.1, C30.1, C31.1, D3#2.2 (A2), D4.1 (K), FB1.2, J1.1, J3.1, J3#2.3, J3#2.4, J4.4 (VDD), J6.3, J11.3, J11.4, R2#2.1, R3#2.1, R4.1, R4#2.2, R5#2.1, R6.2, R10.2, R11.2, R13.2, R14.2, R15.2, R20.2, R21.2, R22.2, R23.2, R24.1, R25.2, R26.1, R35.1, U1.6 (VBAT), U1.11 (VDD), U1.19 (VDD), U1.28 (VDD), U1.50 (VDD), U1.75 (VDD), U1.100 (VDD), U1#2.22 (V_BCKP), U1#2.23 (VCC), U2.2 (VDD), U2.4 (SPI_CS), U2.13 (VDDIO), U2#2.8 (VCC), U3.1 (VDD_I/O), U3.6 (VS), U4.1 (VDDIO), U4.10 (VDD), U5.3 (VDD), U5.11 (VDDIO)
BOOT0: J3.2, R16.1, U1.94 (BOOT0)
BOOT1: R18.1, U1.37 (PB2)
Battery_Sensing: J10.4, U1.15 (PC0)
Buzzer: R30.2, U1.23 (PA0)
CSB_Accel: R25.1, U1.51 (PB12), U5.14 (~CSB1)
CSB_Baro: R26.2, U1.29 (PA4), U4.6 (CSB)
CSB_Flash: R22.1, U1.77 (PA15), U2#2.1 (~CS)
CSB_Gyro: R23.1, U1.48 (PB11), U5.5 (~CSB2)
CSB_HIGH_G: R24.2, U1.33 (PC4), U3.7 (*CS)
CSB_LORA920: J14.7, U1.88 (PD7)
FIRE: J5.2, U1.60 (PD13)
GND: C1.2, C1#2.2, C2.2, C3.2, C4.2, C4#2.2, C5.2, C5#2.2, C6.2, C6#2.2, C7.2, C7#2.2, C8.2, C8#2.2, C9.2, C9#2.2, C10.2, C11.2, C12.2, C13.2, C14.2, C15.2, C16.2, C17.2, C18.2, C19.2, C20.2, C21.2, C22.2, C23.2, C24.2, C25.2, C26.2, C27.2, C28.2, C29.2, C30.2, C31.2, D1.1 (K), D2#2.1 (K), D3#2.1 (A1), GND1.1, J1.4, J1#2.3, J1#2.6, J2.A1 (GND), J2.A12 (GND), J2.B1 (GND), J2.B12 (GND), J2.S1 (SHIELD), J2#2.2 (Ext), J3#2.1, J3#2.2, J4.6 (VSS), J4.10 (SHIELD), J5.3, J5.4, J6.4, J7.1, J7.2, J8.3, J9.3, J9.6, J10.1, J10.2, J11.1, J11.2, J13.3, J13.6, J14.1, Q2.2 (S), R1#2.1, R2.2, R3.2, R16.2, R18.2, R27.1, R28.1, R29.1, R31.2, SW1.1, SW2.1, SW2.SH (B), SW3.1, SW3.SH (B), U1.10 (VSS), U1.20 (VSSA), U1.27 (VSS), U1.74 (VSS), U1.99 (VSS), U1#2.10 (GND), U1#2.12 (GND), U1#2.13 (GND), U1#2.24 (GND), U2.9 (GND), U2.11 (GND), U2#2.4 (GND), U3.2 (GND), U3.4 (GND), U3.5 (GND), U4.3 (VSS), U4.8 (VSS), U4.9 (VSS), U5.2 (GNDA), U5.4 (GNDA), U5.6 (GNDIO), U5.7 (PS), Y1.2 (G), Y1.4 (G)
HSE_IN: C17.1, U1.12 (PH0), Y1.1
HSE_OUT: C18.1, U1.13 (PH1), Y1.3
I2C1_SCL: J1#2.5, J6.1, J9.4, R3#2.2, U1.93 (PB7), U2.1 (SCL/SPI_SCK)
I2C1_SDA: J1#2.4, J6.2, J9.5, R4.2, U1.95 (PB8), U2.16 (SDA/SPI_SDI)
INT_Accel1: U1.38 (PE7), U5.16 (INT1)
INT_Accel2: U1.39 (PE8), U5.1 (INT2)
INT_Baro: U1.36 (PB1), U4.7 (INT)
INT_Gyro1: U1.40 (PE9), U5.12 (INT3)
INT_Gyro2: U1.41 (PE10), U5.13 (INT4)
INT_High_G1: U1.35 (PB0), U3.8 (INT1)
INT_High_G2: U1.34 (PC5), U3.9 (INT2)
INT_Magn: J1#2.7, J9.2, U1.43 (PE12), U2.15 (INT)
LED_SYS: D1#2.2 (A), U1.1 (PE2)
LED_State1: D2.2 (A), U1.2 (PE3)
LED_State2: D3.2 (A), U1.3 (PE4)
LORA433_BUSY: J13.2, U1.42 (PE11)
LORA433_M0: J13.8, U1.58 (PD11)
LORA433_M1: J13.7, U1.57 (PD10)
LORA433_RST: J13.1, U1.59 (PD12)
LORA920_BUSY: J14.8, U1.87 (PD6)
LORA920_INT: J14.3, U1.85 (PD4)
LORA920_RST: J14.2, U1.86 (PD5)
unnamed: BZ1.2 (-), D4.2 (A), Q2.3 (D)
unnamed: D1.2 (A), R1.1
unnamed: D1#2.1 (K), R27.2
unnamed: D2#2.2 (A), R6.1
unnamed: D2.1 (K), R28.2
unnamed: D3.1 (K), R29.2
unnamed: J2.A5 (CC1), R2.1
unnamed: J2.B5 (CC2), R3.1
unnamed: J2#2.1 (In), U1#2.11 (RF_IN)
unnamed: J2.A4 (VBUS), J2.A9 (VBUS), J2.B4 (VBUS), J2.B9 (VBUS), R1#2.2, R12.2
unnamed: Q2.1 (G), R30.1, R31.1
unnamed: R32.1, U1.63 (PC6)
unnamed: R6#2.1, U1.65 (PC8)
unnamed: R7.1, U1.66 (PC9)
unnamed: R8.1, U1.78 (PC10)
unnamed: R9.1, U1.79 (PC11)
unnamed: R19.1, U1.80 (PC12)
unnamed: R33.2, U1.83 (PD2)
unnamed: R17.1, U1.55 (PD8)
unnamed: R5.2, U1#2.21 (RXD_/_SPI_MOSI)
unnamed: TP1.1, U1#2.1 (SAFEBOOT_N)
unnamed: R1.2, U1#2.3 (TIMEPULSE)
unnamed: C8.1, U1.49 (VCAP_1)
unnamed: C9.1, U1.73 (VCAP_2)
unnamed: C4.1, U2.10 (CAP)
unnamed: R20.1, U2#2.7 (~HOLD/~RESET/IO_{3})
unnamed: R21.1, U2#2.3 (~WP/IO_{2})
PWM Servo: J5.1, U1.61 (PD14)
RESET: C3.1, J8.4, R35.2, SW1.2, U1.14 (NRST)
RST_GPS: J1#2.8, J9.1, R2#2.2, U1.67 (PA8), U1#2.8 (RESET_N)
SDIO_CK: J4.5 (CLK), R19.2
SDIO_CMD: J4.3 (CMD), R11.1, R33.1
SDIO_D0: J4.7 (DAT0), R6#2.2, R10.1
SDIO_D1: J4.8 (DAT1), R7.2, R14.1
SDIO_D2: J4.1 (DAT2), R8.2, R15.1
SDIO_D3: J4.2 (DAT3/CD), R9.2, R13.1
SDIO_DET: J4.9 (DET), U1.84 (PD3)
SPI1_MISO: U1.31 (PA6), U3.12 (SDO/ALT_ADDRESS), U4.5 (SDO)
SPI1_MOSI: U1.32 (PA7), U3.13 (SDA/SDI/SDIO), U4.4 (SDI)
SPI1_SCK: U1.30 (PA5), U3.14 (SCL/SCLK), U4.2 (SCK)
SPI2_MISO: U1.53 (PB14), U5.10 (SDO2), U5.15 (SDO1)
SPI2_MOSI: U1.54 (PB15), U5.9 (SDI/SDA)
SPI2_SCK: U1.52 (PB13), U5.8 (SCK/SCL)
SPI3_MISO: J14.4, U1.90 (PB4), U2#2.2 (DO/IO_{1})
SPI3_MOSI: J14.5, U1.91 (PB5), U2#2.5 (DI/IO_{0})
SPI3_SCK: J14.6, U1.89 (PB3), U2#2.6 (CLK)
SUP_STAT: J10.3, U1.16 (PC1)
SWCLK: J1.3, U1.76 (PA14)
SWDIO: J1.2, U1.72 (PA13)
UART3_RX: J13.4, U1.56 (PD9)
UART3_TX: J13.5, R17.2
UART6_RX: J1#2.2, J9.7, U1.64 (PC7), U1#2.20 (TXD_/_SPI_MISO)
UART6_TX: J1#2.1, J9.8, R5.1, R32.2
USART2_RX: J8.1, U1.26 (PA3)
USART2_TX: J8.2, U1.25 (PA2)
USB_D+: J2.A6 (D+), J2.B6 (D+), U1.71 (PA12)
USB_D-: J2.A7 (D-), J2.B7 (D-), U1.70 (PA11)
USB_VBUS: R12.1, U1.68 (PA9)
USER_BT1: C28.1, R4#2.1, SW2.2, U1.24 (PA1)
USER_BT2: C29.1, R5#2.2, SW3.2, U1.18 (PC3)
VREF: C14.1, C15.1, C16.1, FB1.1, U1.21 (VREF+), U1.22 (VDDA)

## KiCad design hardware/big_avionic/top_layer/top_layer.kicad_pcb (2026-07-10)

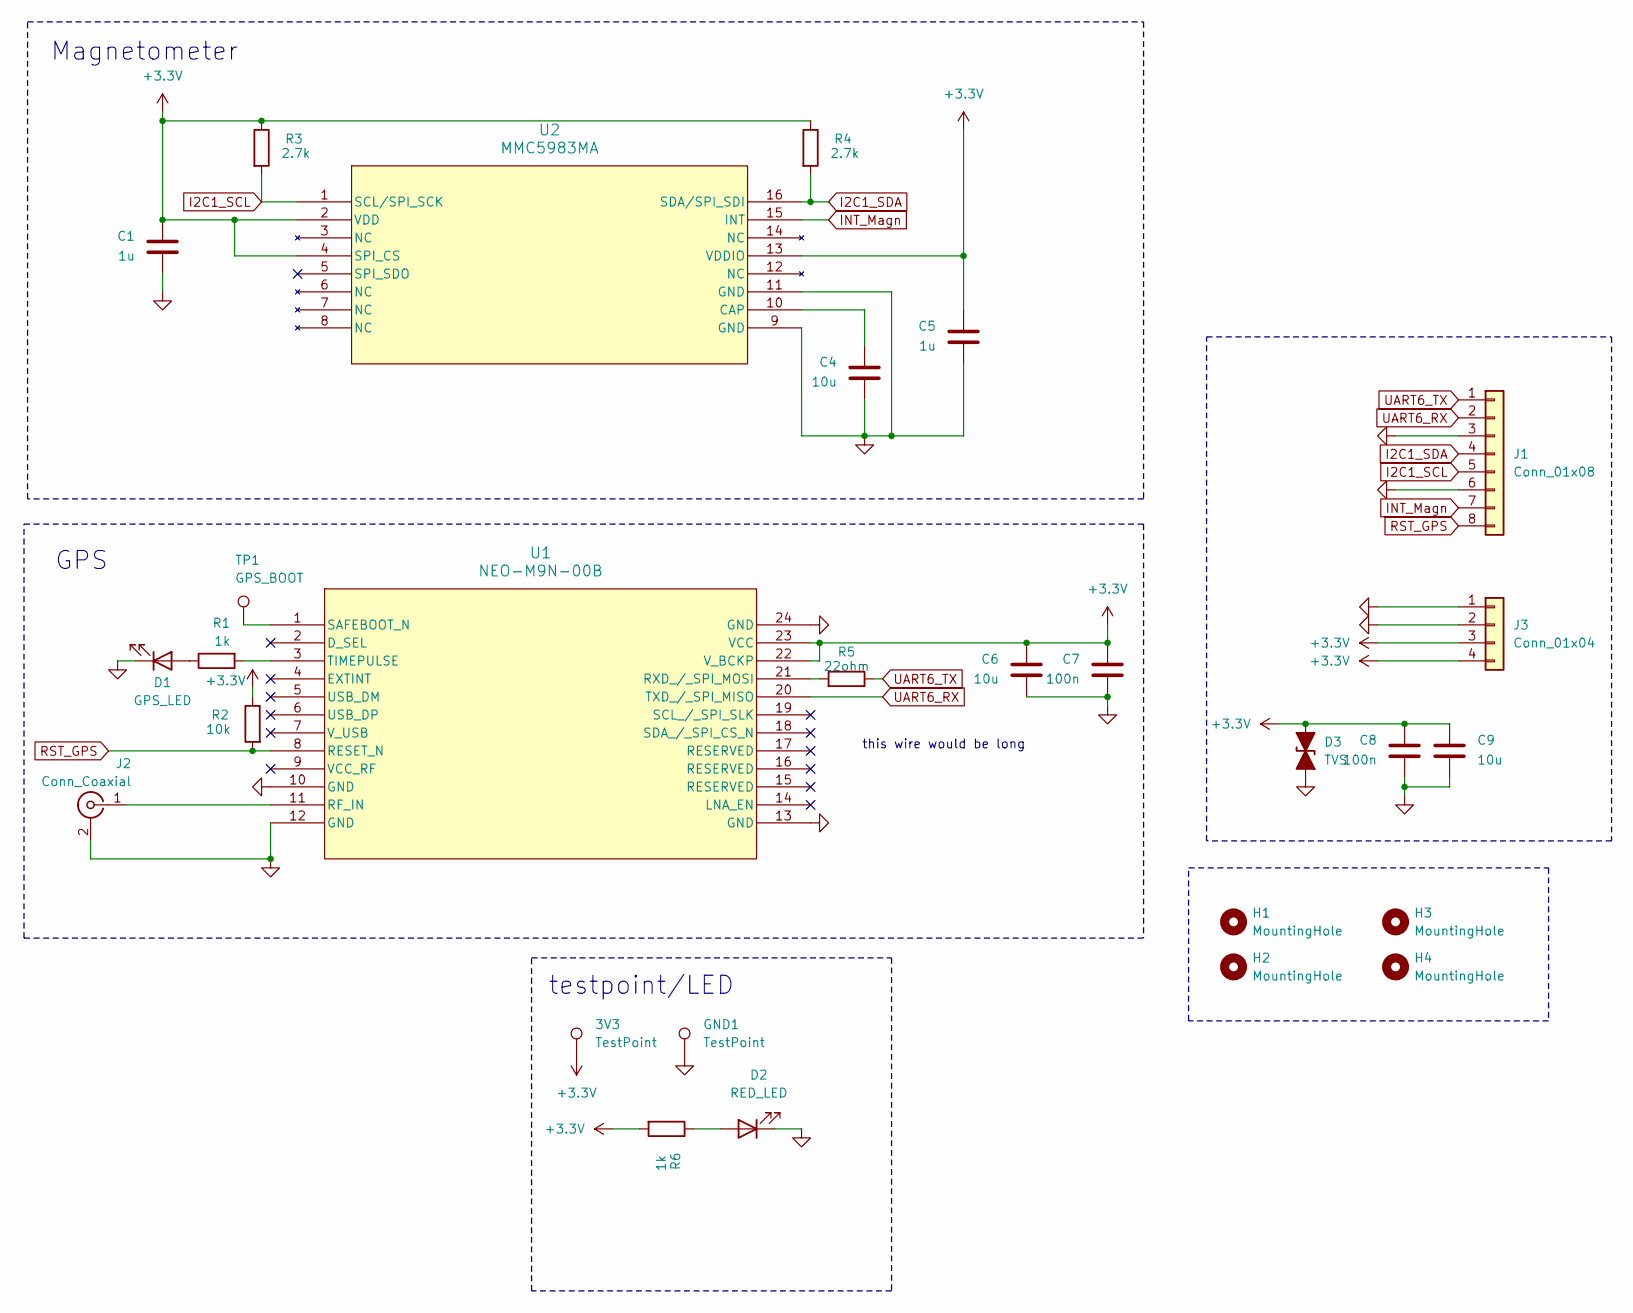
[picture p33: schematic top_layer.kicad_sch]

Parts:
3V3: TestPoint; TestPoint_Pad_D1.0mm
C1, C5: 1u; C_0805_2012Metric_Pad1.18x1.45mm_HandSolder
C4, C6, C9: 10u; C_1206_3216Metric_Pad1.33x1.80mm_HandSolder
C7, C8: 100n; C_0805_2012Metric_Pad1.18x1.45mm_HandSolder
D1: GPS_LED; LED_0805_2012Metric_Pad1.15x1.40mm_HandSolder
D2: RED_LED; LED_0805_2012Metric_Pad1.15x1.40mm_HandSolder
D3: TVS; D_SMA
GND1: TestPoint; TestPoint_Pad_D1.0mm
H1, H2, H3, H4: MountingHole; MountingHole_3.2mm_M3_DIN965_Pad
J1: Conn_01x08; JST_GH_SM08B-GHS-TB_1x08-1MP_P1.25mm_Horizontal
J2: Conn_Coaxial; U.FL_Hirose_U.FL-R-SMT-1_Vertical
J3: Conn_01x04; JST_GH_SM04B-GHS-TB_1x04-1MP_P1.25mm_Horizontal
R1, R6: 1k; R_0805_2012Metric_Pad1.20x1.40mm_HandSolder
R2: 10k; R_0805_2012Metric_Pad1.20x1.40mm_HandSolder
R3, R4: 2.7k; R_0805_2012Metric_Pad1.20x1.40mm_HandSolder
R5: 22ohm; R_0805_2012Metric_Pad1.20x1.40mm_HandSolder
TP1: GPS_BOOT; TestPoint_Pad_D1.0mm
U1: NEO-M9N-00B; SMT_9N-00B_UBL
U2: MMC5983MA; MMC5983MA_MEM

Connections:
+3.3V: 3V3.1, C1.1, C5.1, C6.1, C7.1, C8.1, C9.1, D3.2 (A2), J3.3, J3.4, R2.1, R3.1, R4.1, R6.2, U1.22 (V_BCKP), U1.23 (VCC), U2.2 (VDD), U2.4 (SPI_CS), U2.13 (VDDIO)
GND: C1.2, C4.2, C5.2, C6.2, C7.2, C8.2, C9.2, D1.1 (K), D2.1 (K), D3.1 (A1), GND1.1, J1.3, J1.6, J2.2 (Ext), J3.1, J3.2, U1.10 (GND), U1.12 (GND), U1.13 (GND), U1.24 (GND), U2.9 (GND), U2.11 (GND)
I2C1_SCL: J1.5, R3.2, U2.1 (SCL/SPI_SCK)
I2C1_SDA: J1.4, R4.2, U2.16 (SDA/SPI_SDI)
INT_Magn: J1.7, U2.15 (INT)
unnamed: D1.2 (A), R1.1
unnamed: D2.2 (A), R6.1
unnamed: J2.1 (In), U1.11 (RF_IN)
unnamed: R5.2, U1.21 (RXD_/_SPI_MOSI)
unnamed: TP1.1, U1.1 (SAFEBOOT_N)
unnamed: R1.2, U1.3 (TIMEPULSE)
unnamed: C4.1, U2.10 (CAP)
RST_GPS: J1.8, R2.2, U1.8 (RESET_N)
UART6_RX: J1.2, U1.20 (TXD_/_SPI_MISO)
UART6_TX: J1.1, R5.1

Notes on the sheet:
testpoint/LED
Magnetometer
this wire would be long
GPS

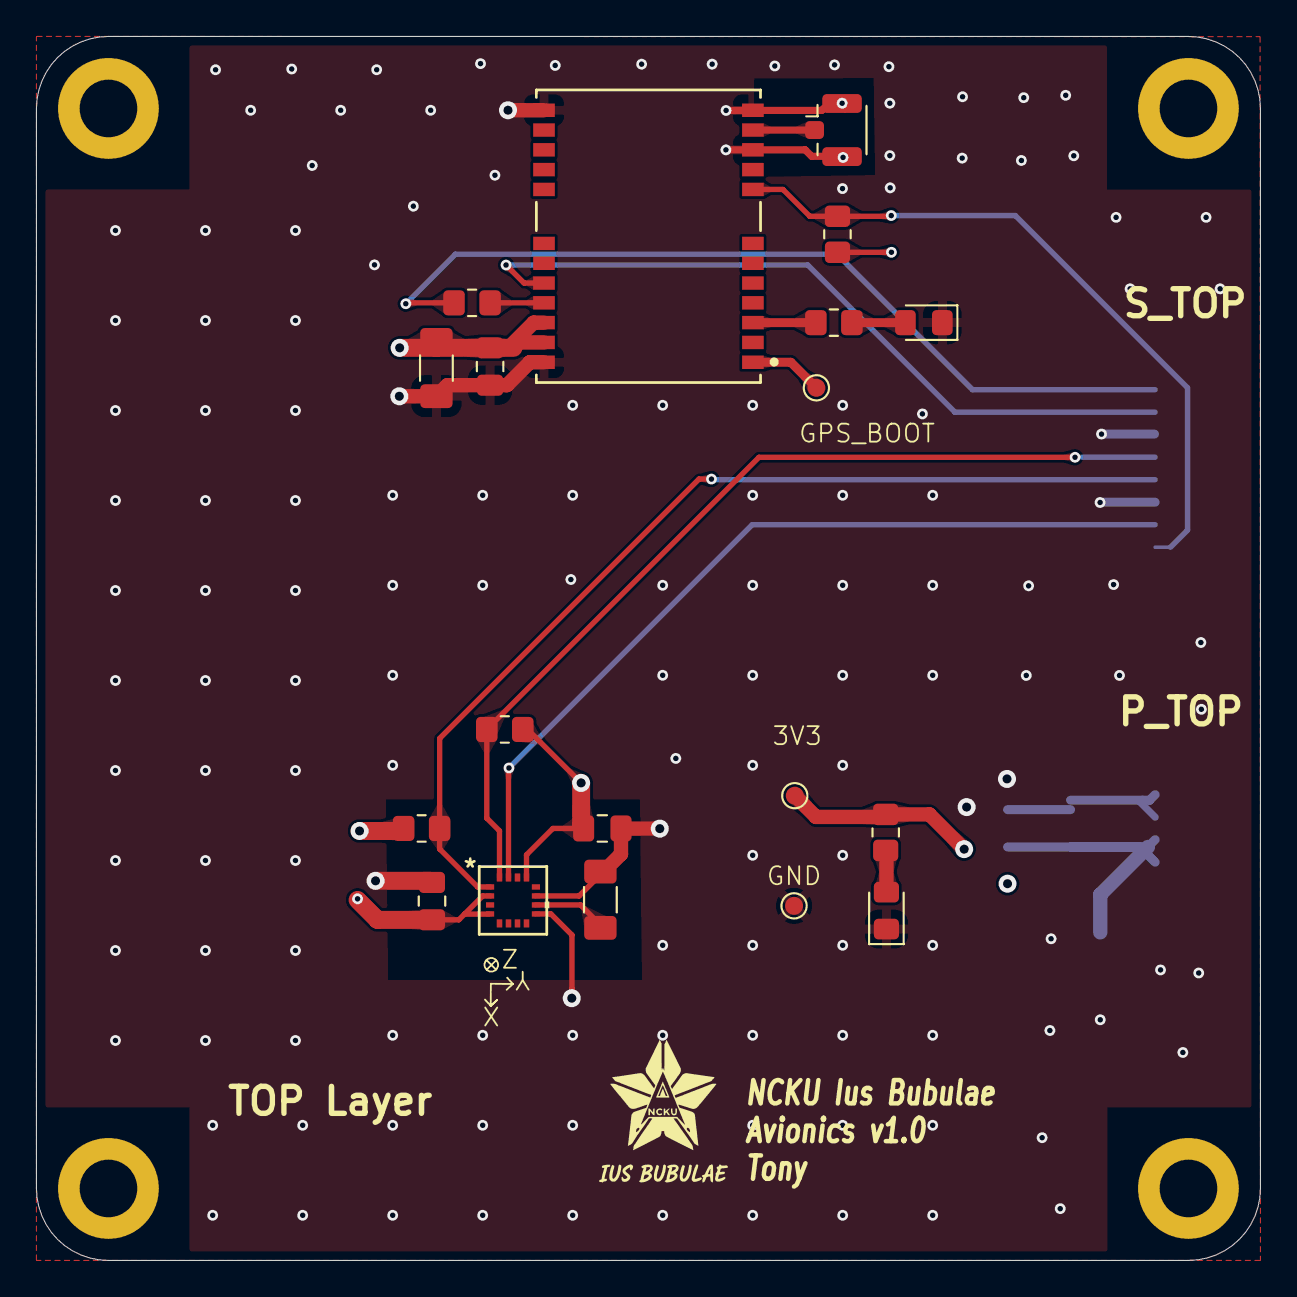
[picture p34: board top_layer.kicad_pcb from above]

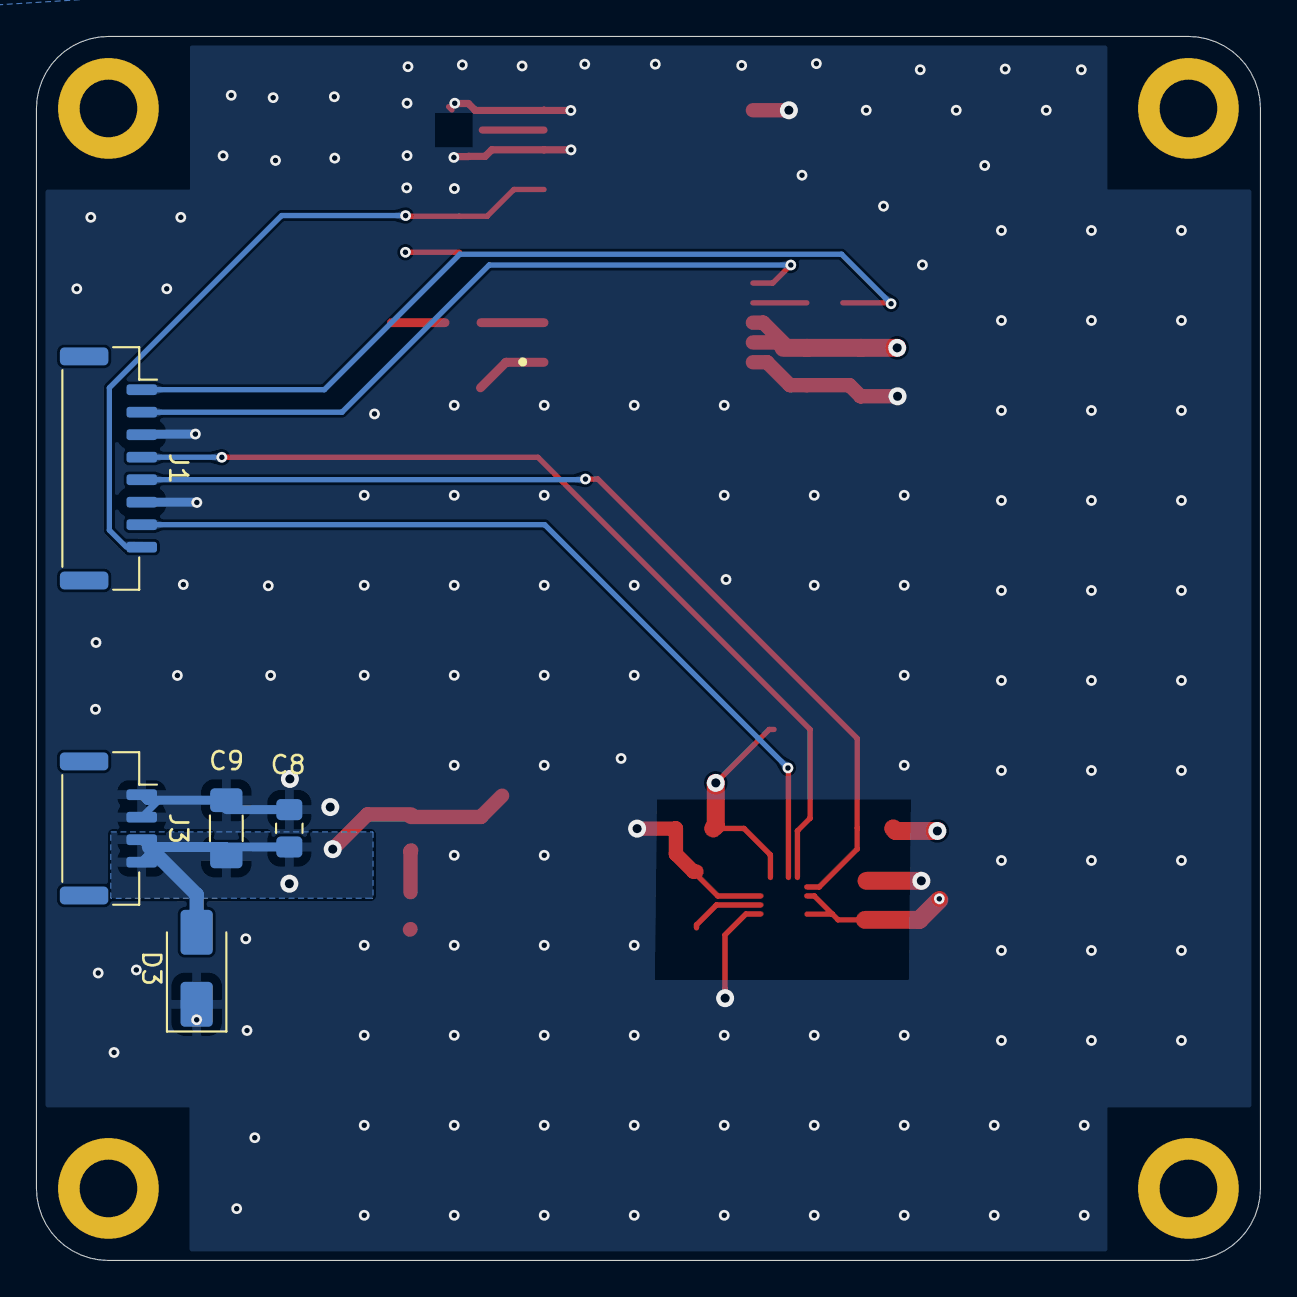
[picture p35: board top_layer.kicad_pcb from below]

Board: 4 copper layers, 68.0 x 68.0 mm, 28 parts (5 on the bottom side), 15 nets.

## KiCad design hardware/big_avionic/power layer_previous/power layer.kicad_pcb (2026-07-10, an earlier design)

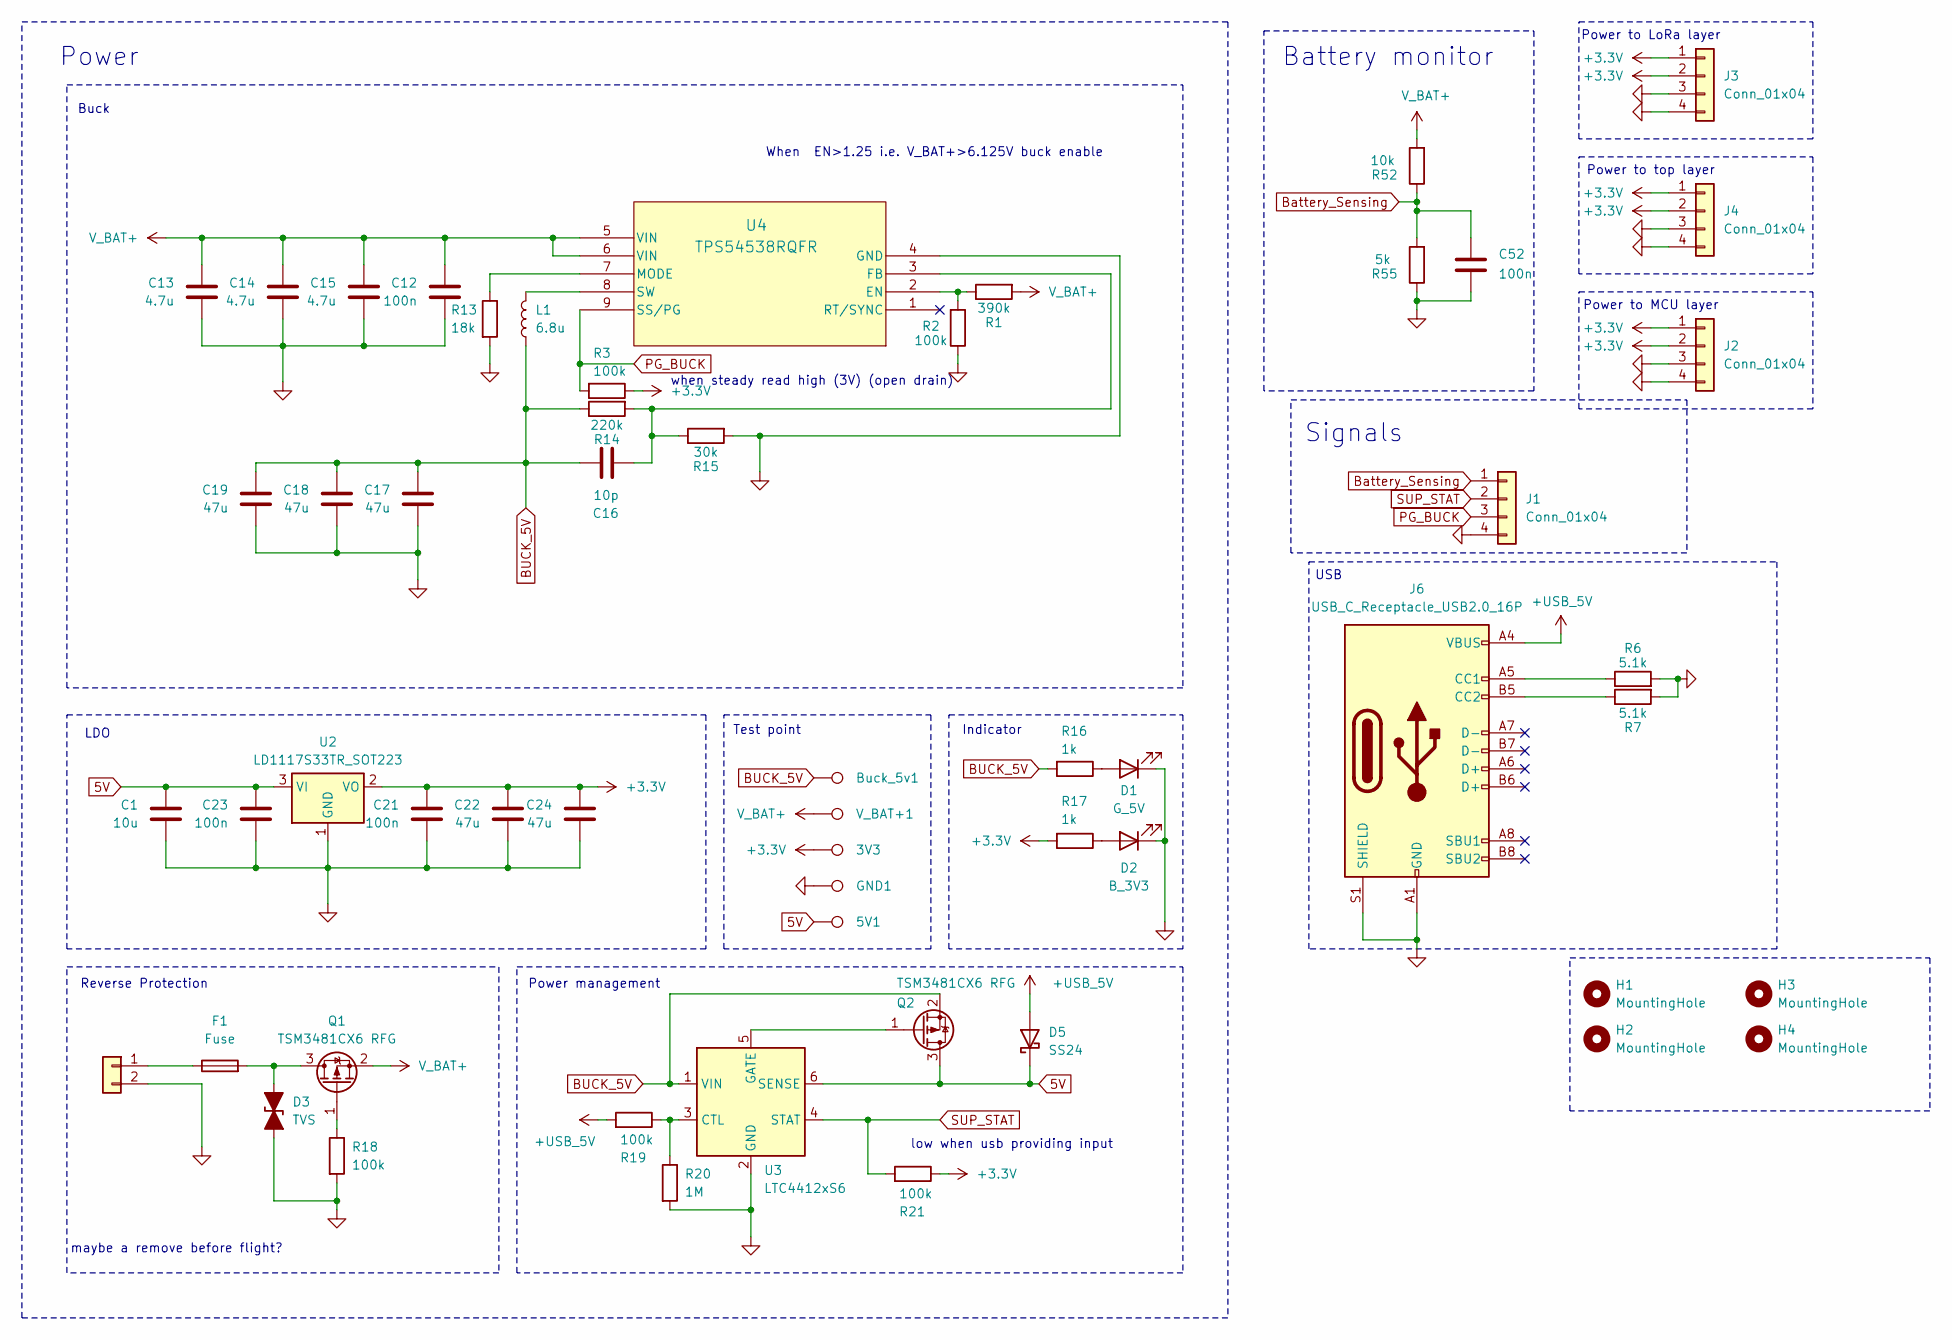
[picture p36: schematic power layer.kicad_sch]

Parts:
3V3: TestPoint; TestPoint_Pad_D1.0mm
5V1: TestPoint; TestPoint_Pad_1.0x1.0mm
Buck_5v1: TestPoint; TestPoint_Pad_D1.0mm
C1: 10u; C_0805_2012Metric_Pad1.18x1.45mm_HandSolder
C12: 100n; C_0603_1608Metric_Pad1.08x0.95mm_HandSolder
C13, C14, C15: 4.7u; C_1206_3216Metric_Pad1.33x1.80mm_HandSolder
C16: 10p; C_0402_1005Metric_Pad0.74x0.62mm_HandSolder
C17, C18, C19, C22, C24: 47u; C_1206_3216Metric_Pad1.33x1.80mm_HandSolder
C21, C23, C52: 100n; C_0805_2012Metric_Pad1.18x1.45mm_HandSolder
D1: G_5V; LED_0805_2012Metric_Pad1.15x1.40mm_HandSolder
D2: B_3V3; LED_0805_2012Metric_Pad1.15x1.40mm_HandSolder
D3: TVS; LED_0805_2012Metric_Pad1.15x1.40mm_HandSolder
D5: SS24; D_SMA
F1: Fuse; Fuse_0805_2012Metric_Pad1.15x1.40mm_HandSolder
GND1: TestPoint; TestPoint_Pad_1.0x1.0mm
H1, H2, H3, H4: MountingHole; MountingHole_3.2mm_M3_DIN965_Pad
J1, J2, J3, J4: Conn_01x04; JST_GH_SM04B-GHS-TB_1x04-1MP_P1.25mm_Horizontal
J5: Conn_01x02; JST_PH_S2B-PH-K_1x02_P2.00mm_Horizontal
J6: USB_C_Receptacle_USB2.0_16P; USB_C_Receptacle_HRO_TYPE-C-31-M-12
L1: 6.8u; L_7.3x7.3_H3.5
Q1, Q2: TSM3481CX6 RFG; SOT-23
R1: 390k; C_0603_1608Metric_Pad1.08x0.95mm_HandSolder
R2, R3, R18, R19, R21: 100k; C_0603_1608Metric_Pad1.08x0.95mm_HandSolder
R6, R7: 5.1k; R_0805_2012Metric_Pad1.20x1.40mm_HandSolder
R13: 18k; C_0603_1608Metric_Pad1.08x0.95mm_HandSolder
R14: 220k; C_0603_1608Metric_Pad1.08x0.95mm_HandSolder
R15: 30k; C_0603_1608Metric_Pad1.08x0.95mm_HandSolder
R16, R17: 1k; C_0603_1608Metric_Pad1.08x0.95mm_HandSolder
R20: 1M; C_0603_1608Metric_Pad1.08x0.95mm_HandSolder
R52: 10k; C_0603_1608Metric_Pad1.08x0.95mm_HandSolder
R55: 5k; C_0603_1608Metric_Pad1.08x0.95mm_HandSolder
U2: LD1117S33TR_SOT223; SOT-223-3_TabPin2
U3: LTC4412xS6; TSOT-23-6
U4: TPS54538RQFR; VQFN-HR9_RQF_TEX(TPS54538)
V_BAT+1: TestPoint; TestPoint_Pad_D1.0mm

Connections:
5V: 5V1.1, C1.1, C23.1, D5.1 (K), Q2.3 (D), U2.3 (VI), U3.6 (SENSE)
+3.3V: 3V3.1, C21.1, C22.1, C24.1, J2.1, J2.2, J3.1, J3.2, J4.1, J4.2, R3.1, R17.2, R21.1, U2.2 (VO)
+USB_5V: D5.2 (A), J6.A4 (VBUS), J6.A9 (VBUS), J6.B4 (VBUS), J6.B9 (VBUS), R19.2
BUCK_5V: Buck_5v1.1, C16.1, C17.1, C18.1, C19.1, L1.1, Q2.2 (S), R14.1, R16.2, U3.1 (VIN)
Battery_Sensing: C52.1, J1.1, R52.1, R55.2
GND: C1.2, C12.2, C13.2, C14.2, C15.2, C17.2, C18.2, C19.2, C21.2, C22.2, C23.2, C24.2, C52.2, D1.1 (K), D2.1 (K), D3.1 (A1), GND1.1, J1.4, J2.3, J2.4, J3.3, J3.4, J4.3, J4.4, J5.2, J6.A1 (GND), J6.A12 (GND), J6.B1 (GND), J6.B12 (GND), J6.S1 (SHIELD), R2.1, R6.2, R7.2, R13.2, R15.2, R18.2, R20.2, R55.1, U2.1 (GND), U3.2 (GND), U4.4 (GND)
unnamed: D1.2 (A), R16.1
unnamed: D2.2 (A), R17.1
unnamed: D3.2 (A2), F1.2, Q1.3 (D)
unnamed: F1.1, J5.1
unnamed: J6.A5 (CC1), R6.1
unnamed: J6.B5 (CC2), R7.1
unnamed: Q1.1 (G), R18.1
unnamed: Q2.1 (G), U3.5 (GATE)
unnamed: R19.1, R20.1, U3.3 (CTL)
unnamed: R1.1, R2.2, U4.2 (EN)
unnamed: C16.2, R14.2, R15.1, U4.3 (FB)
unnamed: R13.1, U4.7 (MODE)
unnamed: L1.2, U4.8 (SW)
PG_BUCK: J1.3, R3.2, U4.9 (SS/PG)
SUP_STAT: J1.2, R21.2, U3.4 (STAT)
V_BAT+: C12.1, C13.1, C14.1, C15.1, Q1.2 (S), R1.2, R52.2, U4.5 (VIN), U4.6 (VIN), V_BAT+1.1

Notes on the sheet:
LDO
Indicator
Power management
USB
Buck
maybe a remove before flight?
Power to MCU layer
Signals
Reverse Protection
Test point
low when usb providing input
Battery monitor
Power
When EN>1.25 i.e. V_BAT+>6.125V buck enable
Power to top layer
Power to LoRa layer
when steady read high (3V) (open drain)

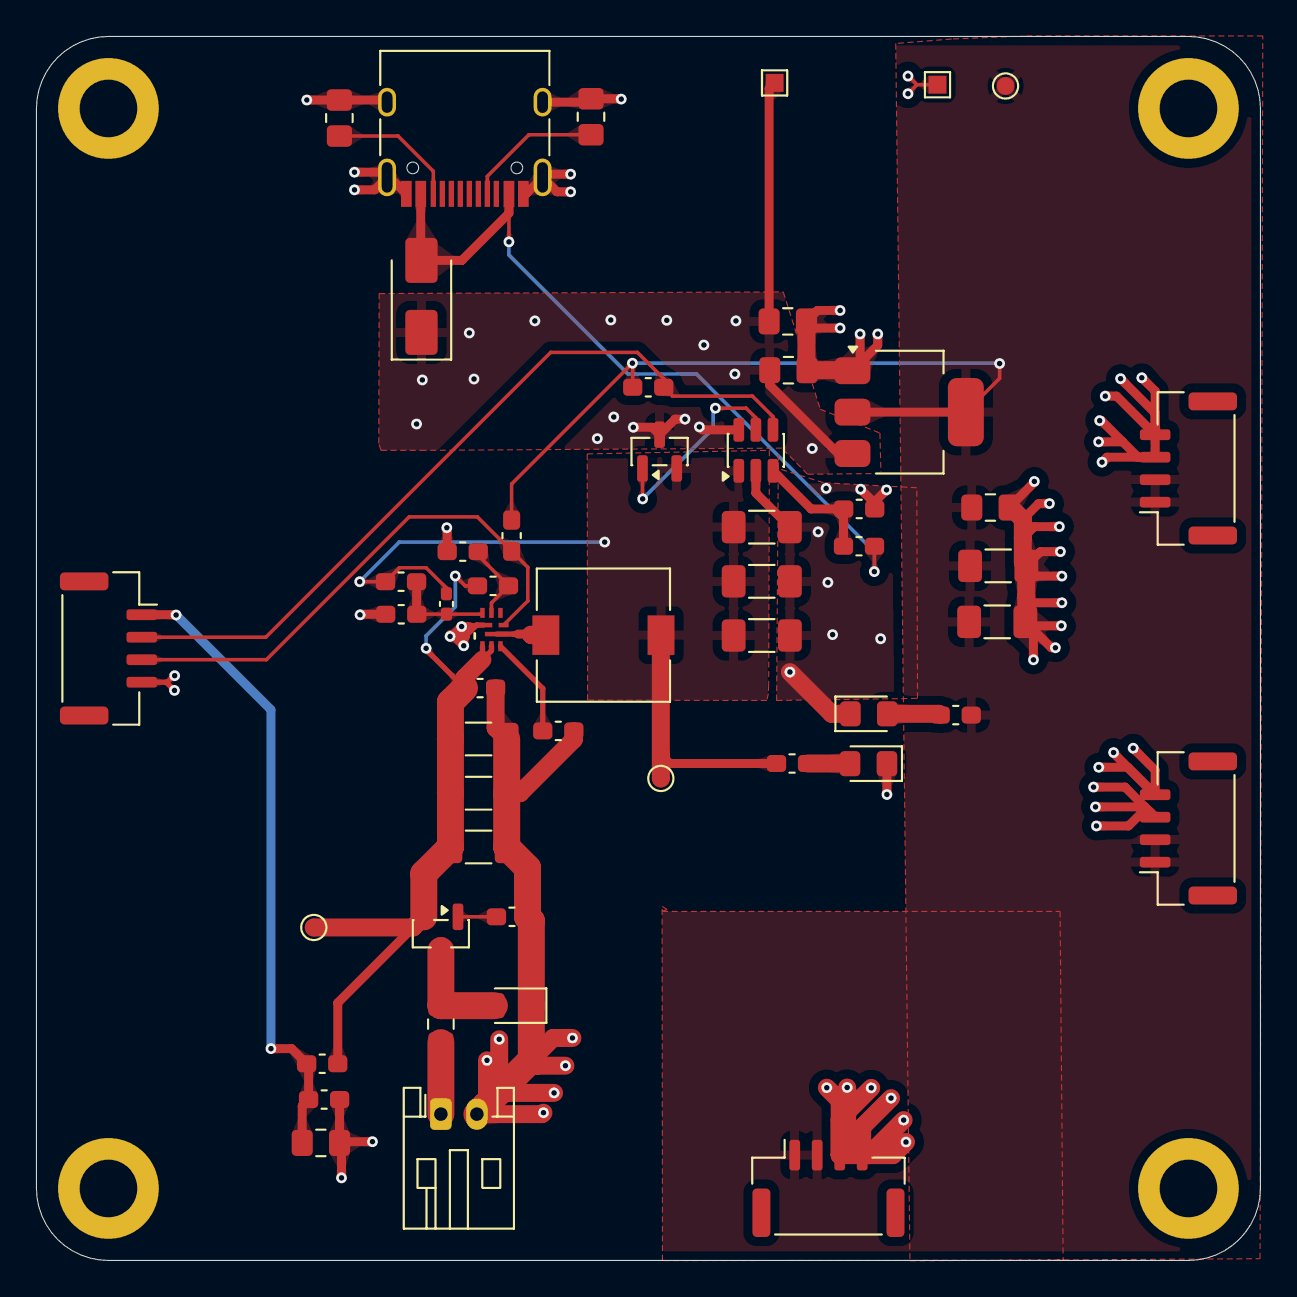
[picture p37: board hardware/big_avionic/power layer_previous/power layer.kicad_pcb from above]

Board: 4 copper layers, 68.0 x 68.0 mm, 56 parts (0 on the bottom side), 22 nets.

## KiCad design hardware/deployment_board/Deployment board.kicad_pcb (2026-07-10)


Board: 4 copper layers, 54.5 x 49.0 mm, 47 parts (0 on the bottom side), 21 nets.

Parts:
3S, 5V: TestPoint; TestPoint_THTPad_D1.5mm_Drill0.7mm
C1, C2, C5, C7, C8, C9: 220uF,865060657012; CP_Elec_10x10.5
C3, C4: 100n,CX0805MRX7R7BB104; C_0805_2012Metric_Pad1.18x1.45mm_HandSolder
D3: TVS,VS15VUA1VWMTFTR; D_TUMD2
D4, D5: LED,AP3216ID; LED_1206_3216Metric_Pad1.42x1.75mm_HandSolder
D6, D7, D8, D9, D11, D12: D_Schottky,PMEG3030EP,115; D_SOD-128
D10: 1N5824; D_5KPW_P12.70mm_Horizontal
F1: Fuse,CC12H15A-TR; Fuse_1206_3216Metric_Pad1.42x1.75mm_HandSolder
GND: TestPoint; TestPoint_THTPad_D1.5mm_Drill0.7mm
H1, H2, H3, H4: MountingHole; MountingHole_2.2mm_M2
J1, J2: Conn_01x02; JST_EH_B2B-EH-A_1x02_P2.50mm_Vertical
J3: Conn_01x02; Molex_Micro-Fit_3.0_43650-0221_1x02_P3.00mm_Vertical
J4, J5: Conn_01x04; JST_GH_BM04B-GHS-TBT_1x04-1MP_P1.25mm_Vertical
J6, J7: Conn_01x02; JST_GH_BM02B-GHS-TBT_1x02-1MP_P1.25mm_Vertical
L1: 33uH,SRN3010BTA-330M; L_Wurth_WE-LQSH-3012
M1, M2: Motor_Servo; PinHeader_1x03_P2.54mm_Vertical
Q1, Q2: IRLML6344TRPBF; SOT-23
Q3: SI7613DN-T1-GE3; Vishay_PowerPAK_1212-8_Single
R1, R4: 220 ohm,1/8W,RG2012P-221-B-T5; R_0805_2012Metric_Pad1.20x1.40mm_HandSolder
R3, R5: 1k,SR0805FR-7W1KL; R_0805_2012Metric_Pad1.20x1.40mm_HandSolder
R7: 100k; R_0805_2012Metric_Pad1.20x1.40mm_HandSolder
R8: 560ohm 1/2W,ERJ-UP6D5600V; R_0805_2012Metric_Pad1.20x1.40mm_HandSolder
R9: 180ohm 1/4W,CRCW0805180RFKEA; R_0805_2012Metric_Pad1.20x1.40mm_HandSolder
U1: LM2596S-5.0/NOPB; TO-263-5_TabPin3

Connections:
2sServo1: D7.1 (K), J6.2, M1.1 (PWM)
2sServo2: D6.1 (K), J6.1, M2.1 (PWM)
3s+: 3S.1 (1_1), C3.2, C4.2, C5.1, C7.1, C9.2, D11.1 (K), D12.1 (K), J1.1, J2.1, Q3.1 (S), Q3.2 (S), Q3.3 (S), R8.2, U1.1 (VIN)
3sMotor1: D9.1 (K), J7.2, R4.2
3sMotor2: D8.1 (K), J7.1, R1.2
5V+: 5V.1 (1_1), C1.1, C2.1, C8.1, L1.2, M1.2 (+), M2.2 (+), R9.2, U1.4 (FEEDBACK)
Backup_AV_FIRE: D9.2 (A), J5.3
Backup_AV_PWM_Servo: D7.2 (A), J5.4
GND: C1.2, C2.2, C5.2, C7.2, C8.2, C9.1, D3.1 (A1), D4.1 (K), D5.1 (K), D10.1 (K), GND.1 (1_1), J3.2, J4.1, J4.2, J5.1, J5.2, M1.3 (-), M2.3 (-), Q1.3 (S), Q2.3 (S), R3.2, R5.2, R7.2, U1.3 (GND), U1.5 (ON_OFF_N)
Main_AV_FIRE: D8.2 (A), J4.3
Main_AV_PWM_Servo: D6.2 (A), J4.4
unnamed: D3.2 (A2), F1.2, Q3.5 (D)
unnamed: D4.2 (A), R8.1
unnamed: D5.2 (A), R9.1
unnamed: D10.2 (A), L1.1, U1.2 (OUTPUT)
unnamed: C3.1, D11.2 (A), J1.2, Q1.1 (D)
unnamed: C4.1, D12.2 (A), J2.2, Q2.1 (D)
unnamed: F1.1, J3.1
unnamed: Q1.2 (G), R1.1, R3.1
unnamed: Q2.2 (G), R4.1, R5.1
unnamed: Q3.4 (G), R7.1

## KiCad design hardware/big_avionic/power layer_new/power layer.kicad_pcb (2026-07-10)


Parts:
3V3_1, 3V3_LORA1, 5V1: TestPoint; TestPoint_Pad_D1.0mm
BU1: R-78K5.0-2.0L; CONV_R-78K5.0-2.0L
BU2: R-78K3.3-2.0L; CONV_R-78K5.0-2.0L
Buck_5v1: TestPoint; TestPoint_Pad_D1.0mm
C1: 10u; C_1210_3225Metric_Pad1.33x2.70mm_HandSolder
C2, C3, C5, C6, C11, C12: 22u; C_1210_3225Metric_Pad1.33x2.70mm_HandSolder
C4, C7, C10, C14, C15: 100n; C_0805_2012Metric_Pad1.18x1.45mm_HandSolder
C8, C9, C13: 47u; C_1210_3225Metric_Pad1.33x2.70mm_HandSolder
C_Damping1, C_Damping2: 22u; CP_EIA-3528-21_Kemet-B_HandSolder
D1: TVS; D_SMA
D2: SS24; D_SMA
D3, D4, D5: LED_0805_2012Metric_Pad1.15x1.40mm_HandSolder
GND1: TestPoint; TestPoint_Pad_D1.0mm
H1, H2, H3, H4: MountingHole; MountingHole_3.2mm_M3_DIN965_Pad
J1: Conn_01x02; JST_PH_S2B-PH-K_1x02_P2.00mm_Horizontal
J2: USB_C_Receptacle_USB2.0_16P; USB_C_Receptacle_HRO_TYPE-C-31-M-12
J3, J4, J5, J6: Conn_01x04; JST_GH_SM04B-GHS-TB_1x04-1MP_P1.25mm_Horizontal
L1, L2: 4.7uH; L_APV_ANR4020
Q1, Q2: AO3401A; SOT-23
R1, R2: 100k; R_0805_2012Metric_Pad1.20x1.40mm_HandSolder
R3: 1M; R_0805_2012Metric_Pad1.20x1.40mm_HandSolder
R4: 470k; R_0805_2012Metric_Pad1.20x1.40mm_HandSolder
R5: 330; R_0805_2012Metric_Pad1.20x1.40mm_HandSolder
R6, R11: 100; R_0805_2012Metric_Pad1.20x1.40mm_HandSolder
R7: 10k; R_0805_2012Metric_Pad1.20x1.40mm_HandSolder
R8: 5k; R_0805_2012Metric_Pad1.20x1.40mm_HandSolder
R9, R10: 5.1k; R_0805_2012Metric_Pad1.20x1.40mm_HandSolder
U1: LD1117S33TR_SOT223; SOT-223-3_TabPin2
U2: LTC4412xS6; TSOT-23-6
V_BAT+1: TestPoint; TestPoint_Pad_D1.0mm

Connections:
5V: 5V1.1, C1.1, C3.1, C4.1, C13.2, D2.1 (K), L2.1, Q2.2 (S), R5.2, U1.3 (VI), U2.6 (SENSE)
+3.3V: 3V3_1.1, C7.1, C8.1, C9.1, J4.1, J4.2, J5.1, J5.2, R4.1, R6.2, U1.2 (VO)
+3.3V_LoRa: 3V3_LORA1.1, BU2.3 (VOUT), C12.1, C15.1, J6.1, J6.2, R11.2
+USB_5V: D2.2 (A), J2.A4 (VBUS), J2.A9 (VBUS), J2.B4 (VBUS), J2.B9 (VBUS), R2.2
BUCK_5V: BU1.3 (VOUT), Buck_5v1.1, C10.2, C11.1, Q2.3 (D), U2.1 (VIN)
Battery_Sensing: C14.1, J3.1, R7.1, R8.2
GND: BU1.2 (GND), BU2.2 (GND), C1.2, C2.2, C3.2, C4.2, C5.2, C6.2, C7.2, C8.2, C9.2, C10.1, C11.2, C12.2, C13.1, C14.2, C15.2, C_Damping1.2, C_Damping2.2, D1.1 (A1), D3.1 (K), D4.1 (K), D5.1 (K), GND1.1, J1.2, J2.A1 (GND), J2.A12 (GND), J2.B1 (GND), J2.B12 (GND), J2.S1 (SHIELD), J3.3, J3.4, J4.3, J4.4, J5.3, J5.4, J6.3, J6.4, R1.2, R3.2, R8.1, R9.2, R10.2, U1.1 (GND), U2.2 (GND)
unnamed: BU1.1 (VIN), C5.1, C_Damping2.1, L1.2
unnamed: BU2.1 (VIN), C6.1, C_Damping1.1, L2.2
unnamed: D1.2 (A2), J1.1, Q1.3 (D)
unnamed: D3.2 (A), R5.1
unnamed: D4.2 (A), R6.1
unnamed: D5.2 (A), R11.1
unnamed: J2.A5 (CC1), R9.1
unnamed: J2.B5 (CC2), R10.1
unnamed: Q1.1 (G), R1.1
unnamed: Q2.1 (G), U2.5 (GATE)
unnamed: R2.1, R3.1, U2.3 (CTL)
SUP_STAT: J3.2, R4.2, U2.4 (STAT)
V_BAT+: C2.1, L1.1, Q1.2 (S), R7.2, V_BAT+1.1

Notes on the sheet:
LDO
Indicator
maybe a pi filter in oupput also
Power selection
USB
Buck->5V
maybe a remove before flight?
buck LoRa->3V3
Power to MCU layer
Signals
Reverse Protection
Test point
low when usb providing input(10uA current sink)
Battery monitor
Power
Power to top layer
Power to LoRa layer


Board: 4 copper layers, 68.0 x 68.0 mm, 57 parts (0 on the bottom side), 20 nets.

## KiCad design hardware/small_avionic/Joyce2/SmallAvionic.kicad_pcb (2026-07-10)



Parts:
3V1: TestPoint; TestPoint_THTPad_D2.0mm_Drill1.0mm
BU101: FanPinHeader_1x03_P2.54mm_Vertical
BZ1: Active Buzzer; Buzzer_15x7.5RM7.6
Buck_5v1: TestPoint; TestPoint_THTPad_D2.0mm_Drill1.0mm
C1, C31: 10u; C_0805_2012Metric_Pad1.18x1.45mm_HandSolder
C2, C3, C4, C6, C8, C11, C13, C18, C24, C26, C27, C28, C29, C30, C33: 100n; C_0805_2012Metric_Pad1.18x1.45mm_HandSolder
C16, C17: 47u; C_0805_2012Metric_Pad1.18x1.45mm_HandSolder
C20, C23, C32, C104: 1u; C_0805_2012Metric_Pad1.18x1.45mm_HandSolder
C21, C22: 22pF; C_0805_2012Metric_Pad1.18x1.45mm_HandSolder
C25: 4.7u; C_0805_2012Metric_Pad1.18x1.45mm_HandSolder
C101: 330u; CP_Radial_D6.3mm_P2.50mm
C102: 22u; C_0805_2012Metric_Pad1.18x1.45mm_HandSolder
C103: 2.2u; C_0805_2012Metric_Pad1.18x1.45mm_HandSolder
D1: TVS; D_SMA-SMB_Universal_Handsoldering
D2: G_5V; LED_0805_2012Metric_Pad1.15x1.40mm_HandSolder
D3: B_3V3; LED_0805_2012Metric_Pad1.15x1.40mm_HandSolder
D4: G; LED_0805_2012Metric_Pad1.15x1.40mm_HandSolder
D5: R; LED_0805_2012Metric_Pad1.15x1.40mm_HandSolder
D6: 1N4148; D_DO-35_SOD27_P7.62mm_Horizontal
F1: Fuse; Fuse_1206_3216Metric_Pad1.42x1.75mm_HandSolder
FB1: FerriteBead 120R @ 100M; L_0805_2012Metric_Pad1.05x1.20mm_HandSolder
GND1: TestPoint; TestPoint_THTPad_D2.0mm_Drill1.0mm
H1, H2, H3, H4: MountingHole; MountingHole_2.2mm_M2
J1: Conn_01x02; Molex_Micro-Fit_3.0_43650-0221_1x02_P3.00mm_Vertical
J2: Boot_mode_pin; PinSocket_1x02_P2.00mm_Vertical
J3: Conn_01x04; PinSocket_1x04_P2.00mm_Vertical
J4: USB_C_Receptacle_USB2.0_16P; USB_C_Receptacle_HCTL_HC-TYPE-C-16P-01A
J5, J8: Conn_01x03; JST_GH_BM03B-GHS-TBT_1x03-1MP_P1.25mm_Vertical
J6: Conn_01x04; JST_EH_B4B-EH-A_1x04_P2.50mm_Vertical
J7: Screw_Terminal_01x01; TerminalBlock_MetzConnect_360271_1x01_Horizontal_ScrewM3.0_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
J9: Conn_01x02; JST_EH_B2B-EH-A_1x02_P2.50mm_Vertical
L101, L102: 1mH; L_0805_2012Metric_Pad1.05x1.20mm_HandSolder
Q1, Q2: TSM3481CX6 RFG; SOT-23
Q3: NMOS; TO-252-2
R1, R2, R20, R21, R22, R26, R27, R29, R30, R32: 10k; R_0805_2012Metric_Pad1.20x1.40mm_HandSolder
R3, R5, R9: 100k; R_0805_2012Metric_Pad1.20x1.40mm_HandSolder
R7: 1M; R_0805_2012Metric_Pad1.20x1.40mm_HandSolder
R10: 0 ohm; R_0805_2012Metric_Pad1.20x1.40mm_HandSolder
R13, R14: 22ohm; R_0805_2012Metric_Pad1.20x1.40mm_HandSolder
R15, R16, R28: 1k; R_0805_2012Metric_Pad1.20x1.40mm_HandSolder
R17: 1.5k; R_0805_2012Metric_Pad1.20x1.40mm_HandSolder
R18, R19: 5.1k; R_0805_2012Metric_Pad1.20x1.40mm_HandSolder
R23, R31: 2.7k; R_0805_2012Metric_Pad1.20x1.40mm_HandSolder
R24, R25: 2.2k; R_0805_2012Metric_Pad1.20x1.40mm_HandSolder
R40: 5k; R_0805_2012Metric_Pad1.20x1.40mm_HandSolder
SW1: SW_Push; SW_Push_1P1T_NO_E-Switch_TL3301NxxxxxG
SW2: USER_Buttom; SW_Push_1P1T_NO_E-Switch_TL3301NxxxxxG
U1: LD1117S33TR_SOT223; SOT-223-3_TabPin2
U2: STM32F103C8Tx; LQFP-48_7x7mm_P0.5mm
U3: LTC4412xS6; TSOT-23-6
U5: MMC5983MA; MMC5983MA_MEM
U6: BMP390; 10LGA_2X2X0p75_BOS
U7: W25Q128JVS; SOIC-8_5.3x5.3mm_P1.27mm
U8: BMI088; Bosch_LGA-16_4.5x3mm_P0.5mm_LayoutBorder7x1y_ClockwisePinNu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
V_BAT+1: TestPoint; TestPoint_THTPad_D2.0mm_Drill1.0mm
Y1: 8Mhz; Crystal_SMD_0603-4Pin_6.0x3.5mm_HandSoldering

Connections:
+3.3V: 3V1.1, C1.1, C2.1, C3.1, C8.1, C11.1, C13.1, C16.1, C17.1, C23.1, C24.1, C25.1, C26.1, C27.1, C28.1, C29.1, C32.1, FB1.2, J2.1, J3.1, J6.3, R9.1, R16.2, R17.2, R20.2, R21.2, R22.2, R23.1, R26.2, R27.2, R30.1, R31.1, U1.2 (VO), U2.1 (VBAT), U2.24 (VDD), U2.36 (VDD), U2.48 (VDD), U5.2 (VDD), U5.4 (SPI_CS), U5.13 (VDDIO), U6.1 (VDDIO), U6.10 (VDD), U7.8 (VCC), U8.3 (VDD), U8.11 (VDDIO)
+USB_5V: J4.A4 (VBUS), J4.A9 (VBUS), J4.B4 (VBUS), J4.B9 (VBUS), Q2.3 (D), R5.2, U3.6 (SENSE)
BOOT0: J2.2, R2.1, U2.44 (BOOT0)
BOOT1: R1.1, U2.20 (PB2)
BUCK_5V: BU101.3 (VOUT), Buck_5v1.1, C6.1, C102.1, Q2.2 (S), R15.2, U1.3 (VI), U3.1 (VIN)
Battery_Sensing: C33.1, R32.1, R40.2, U2.19 (PB1)
Buzzer: R28.2, U2.22 (PB11)
CSB_Accel: R27.1, U2.14 (PA4), U8.14 (~CSB1)
CSB_Baro: R30.2, U2.18 (PB0), U6.6 (CSB)
CSB_Flash: R26.1, U2.29 (PA8), U7.1 (~CS)
CSB_Gyro: R22.1, U2.13 (PA3), U8.5 (~CSB2)
FIRE: J5.2, U2.45 (PB8)
GND: BU101.2 (GND), C1.2, C2.2, C3.2, C4.2, C6.2, C8.2, C11.2, C13.2, C16.2, C17.2, C18.2, C20.2, C21.2, C22.2, C23.2, C24.2, C25.2, C26.2, C27.2, C28.2, C29.2, C30.2, C31.2, C32.2, C33.2, C102.2, C104.2, D1.1 (A1), D2.1 (K), D3.1 (K), GND1.1, J1.2, J3.4, J4.A1 (GND), J4.A12 (GND), J4.B1 (GND), J4.B12 (GND), J4.S1 (SHIELD), J5.3, J6.4, J7.1, J8.3, L102.2, Q3.3 (S), R1.2, R2.2, R3.2, R7.2, R18.2, R19.2, R24.1, R25.1, R29.2, R40.1, SW1.1, SW2.1, U1.1 (GND), U2.8 (VSSA), U2.23 (VSS), U2.35 (VSS), U2.47 (VSS), U3.2 (GND), U5.9 (GND), U5.11 (GND), U6.3 (VSS), U6.8 (VSS), U6.9 (VSS), U7.4 (GND), U8.2 (GNDA), U8.4 (GNDA), U8.6 (GNDIO), U8.7 (PS), Y1.2 (G), Y1.4 (G)
HSE_IN: C21.1, U2.5 (PD0), Y1.1
HSE_OUT: R10.1, U2.6 (PD1), Y1.3
I2C1_SCL: J6.1, R23.2, U2.42 (PB6), U5.1 (SCL/SPI_SCK)
I2C1_SDA: J6.2, R31.2, U2.43 (PB7), U5.16 (SDA/SPI_SDI)
INT_Accel1: U2.10 (PA0), U8.16 (INT1)
INT_Accel2: U2.11 (PA1), U8.1 (INT2)
INT_Baro: U2.21 (PB10), U6.7 (INT)
INT_Gyro: U2.12 (PA2), U8.12 (INT3)
INT_Magn: U2.41 (PB5), U5.15 (INT)
LED_SYS: D4.2 (A), U2.2 (PC13)
LED_State: D5.2 (A), U2.3 (PC14)
NRST: C4.1, SW1.2, U2.7 (NRST)
unnamed: BU101.1 (VIN), C104.1, L101.2
unnamed: BZ1.2 (-), D6.2 (A), Q3.1 (D)
unnamed: C22.1, R10.2
unnamed: C101.2, C103.2, L102.1
unnamed: D1.2 (A2), F1.2, J9.2, Q1.3 (D)
unnamed: D2.2 (A), R15.1
unnamed: D3.2 (A), R16.1
unnamed: D4.1 (K), R24.2
unnamed: D5.1 (K), R25.2
unnamed: F1.1, J1.1
unnamed: J4.A5 (CC1), R18.1
unnamed: J4.B5 (CC2), R19.1
unnamed: J4.A6 (D+), J4.B6 (D+), R14.2
unnamed: J4.A7 (D-), J4.B7 (D-), R13.1
unnamed: Q1.1 (G), R3.1
unnamed: Q2.1 (G), U3.5 (GATE)
unnamed: Q3.2 (G), R28.1, R29.1
unnamed: C18.1, C20.1, FB1.1, U2.9 (VDDA)
unnamed: R5.1, R7.1, U3.3 (CTL)
unnamed: C31.1, U5.10 (CAP)
unnamed: R20.1, U7.7 (~HOLD/~RESET/IO_{3})
PWM Servo: J5.1, U2.46 (PB9)
SPI1_MISO: U2.16 (PA6), U6.5 (SDO), U8.10 (SDO2), U8.15 (SDO1)
SPI1_MOSI: U2.17 (PA7), U6.4 (SDI), U8.9 (SDI/SDA)
SPI1_SCK: U2.15 (PA5), U6.2 (SCK), U8.8 (SCK/SCL)
SPI2_MISO: U2.27 (PB14), U7.2 (DO/IO_{1})
SPI2_MOSI: U2.28 (PB15), U7.5 (DI/IO_{0})
SPI2_SCK: U2.26 (PB13), U7.6 (CLK)
SUP_STAT: R9.2, U2.40 (PB4), U3.4 (STAT)
SWCLK: J3.3, U2.37 (PA14)
SWDIO: J3.2, U2.34 (PA13)
USART1_RX: J8.2, U2.31 (PA10)
USART1_TX: J8.1, U2.30 (PA9)
USB_D+: R14.1, R17.1, U2.33 (PA12)
USB_D-: R13.2, U2.32 (PA11)
USER_BT: C30.1, SW2.2, U2.4 (PC15)
V_BAT+: BZ1.1 (+), C101.1, C103.1, D6.1 (K), J9.1, L101.1, Q1.2 (S), R32.2, V_BAT+1.1
WP_Flash: R21.1, U2.25 (PB12), U7.3 (~WP/IO_{2})

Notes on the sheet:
C33濾波
Power
C32濾波
讓大小航電板共地
用USB供電 &防止電池電流倒灌到USB
common ground to Main_AV GND
decoupling
UART communication
V=BAT(8.4)*5/(5+10)=2.8V
Battery monitor
Flash
決定開機後要正常執行or重灌
3.3V是用於open-drain，並非電源輸出
Buck
把5V再轉為3.3V給mcu跟感測器用
Indicator
C4去彈跳電容， 吸收雜訊
clock
Connection to Main_AV
狀態輸出腳位
External reset
C30濾波
IMU
Buttom
PB12 GPIO_OUT
C27在VCC旁邊 C25在3.3V旁
磁珠:抑制高頻雜訊
LDO
SDA、SCL要上拉
maybe a remove before flight?
47uF(tantalum capacitor
C26C29要記得放在VDD、VDDIO旁邊
Serial Wire Debug
C21C22負載電容， 負責與石英晶體共振
buck_5V再接到LDO
Remove Before Flight
CSB上拉
防反向突波
Ignition connector
Boot&Debug


Board: 4 copper layers, 76.8 x 61.5 mm, 99 parts (0 on the bottom side), 63 nets.

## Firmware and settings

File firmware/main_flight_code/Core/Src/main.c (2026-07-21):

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
/* Includes ------------------------------------------------------------------*/
#include "main.h"
#include "cmsis_os.h"
#include "fatfs.h"

/* USER CODE BEGIN Includes */
#include "bmi088.h"
#include "adxl375.h"
#include "bmp388.h"
#include "w25qxx.h"
#include "rate_monitor.h"  /* 採樣率監測模組，要停用請在 rate_monitor.h 註解 #define RATE_MONITOR_ENABLE */
#include "ekf.h"
#include "gps.h"
#include "mmc5983.h"
#include "sensor_axis.h"   /* 感測器->body 軸向映射（唯一真相來源，見 sensor_axis.h） */
#include "telemetry.h"     /* 共用二進制+CRC16 下行遙測封包 */
#include "sensor_health.h" /* P0-D：感測器失流/卡死/範圍偵測（host 可測純邏輯） */
#include "lora_e22.h"      /* E22-400T30S 433MHz LoRa 透傳 (UART3) */
#include "lora_e80.h"      /* E80-900M2213S 920MHz LoRa (SX126x SPI3) */
#include "spi3_bus.h"      /* SPI3 共用匯流排互斥鎖 (Flash + E80) */
#include "board_config.h"  /* 主/備角色與功能旗標（單一程式碼雙板） */
#include "link_hw.h"       /* 板間鏈路（USART2 全雙工）；FEATURE_LINK 下編入 */
#include "ground_station.h" /* 地面站主流程（IS_GROUND 下編入；其餘角色為空） */
#include "pyro_selftest.h" /* 開傘 PWM 舵機地面自測（FEATURE_PYRO_SELFTEST 下編入；平時為空） */
#include "gs_lora_test.h"   /* 地面站 LoRa 通訊測試模組（UART2 命令 + 雙鏈路統計） */
#include "uplink_cmd.h"     /* 上行手動開傘（FEATURE_UPLINK_DEPLOY 下編入；其餘為空） */
#include "usb_device.h"     /* USB-CDC 初始化（FEATURE_USB_CDC 下啟用） */
#include "usbd_cdc_if.h"    /* CDC_Transmit_FS（FEATURE_USB_DEBUG_LOG 下 printf 直通 USB 用） */
#include "ack_proto.h"      /* 命令 ACK 幀 + ACK_OK/UNKNOWN/... 狀態碼（遠端指令回覆） */
#include "uplink_text_proto.h" /* UPLINK_TEXT_MAX（遠端文字命令緩衝大小） */
#include "vertical_filter.h" /* 垂直通道 3 狀態 Kalman（FEATURE_VFILTER 下於 FSM_Update 接線） */
/* 版本資訊：版號為 board_config.h 的 FIRMWARE_VERSION（手動語意化版本）。
 * Makefile 建置前自動產生 build_version.h，補上 git 版次(FW_GIT) 與建置時間(FW_BUILD)；
 * 未經 Makefile（如直接用 CubeIDE）建置時該檔不存在 → 退回預設，不影響編譯。 */
#if defined(__has_include)
#  if __has_include("build_version.h")
#    include "build_version.h"
#  endif
#endif
#ifndef FW_GIT
#define FW_GIT   "nogit"
#endif
#ifndef FW_BUILD
#define FW_BUILD (__DATE__ " " __TIME__)
#endif
#include <stdio.h>
#include <string.h>
#include <stdlib.h>   /* strtoul/atoi：命令台參數解析 */
#include <ctype.h>    /* tolower：命令台小寫化 */
#include <math.h>
#include "lora_calc.h" /* LoRa 純換算（BW/LDRO/E22 CH）：命令台參數檢查與顯示 */
/* USER CODE END Includes */

ADC_HandleTypeDef hadc1;

CRC_HandleTypeDef hcrc;

I2C_HandleTypeDef hi2c1;

IWDG_HandleTypeDef hiwdg;

RNG_HandleTypeDef hrng;

RTC_HandleTypeDef hrtc;

SD_HandleTypeDef hsd;
DMA_HandleTypeDef hdma_sdio;

SPI_HandleTypeDef hspi1;
SPI_HandleTypeDef hspi2;
SPI_HandleTypeDef hspi3;

TIM_HandleTypeDef htim2;
TIM_HandleTypeDef htim3;
TIM_HandleTypeDef htim4;
TIM_HandleTypeDef htim6;
TIM_HandleTypeDef htim7;

UART_HandleTypeDef huart2;
UART_HandleTypeDef huart3;
UART_HandleTypeDef huart6;
DMA_HandleTypeDef hdma_usart2_rx;
DMA_HandleTypeDef hdma_usart6_rx;
DMA_HandleTypeDef hdma_i2c1_rx; // Dummy handle to prevent linker/compiler errors in generated code

PCD_HandleTypeDef hpcd_USB_OTG_FS;

/* Definitions for defaultTask */
osThreadId_t defaultTaskHandle;
const osThreadAttr_t defaultTask_attributes = {
  .name = "defaultTask",
  .stack_size = 512 * 4,  /* 2048 bytes: Bosch BMP3 API 深度呼叫 + VLA 需要足夠的堆疊空間 */
  .priority = (osPriority_t) osPriorityNormal,
};
/* USER CODE BEGIN PV */
#define ENABLE_DIAGNOSTICS 1  /* 註解此行即可完全關閉診斷任務以節省資源 */

volatile float g_main_task_cpu_usage = 0.0f;
FlightState_t current_fsm_state = STATE_INIT;   /* 由 FSM 包裝層自 g_fsm_ctx 鏡射（P0-A） */
uint32_t flight_start_tick = 0;                 /* 同上；速度歷史 last_vel_z 已收入 FSM_Context_t */
uint8_t sd_logging_active = 0;

/* P1：任務堆疊水位觀測用 handle（defaultTask 用 CubeMX 既有的 defaultTaskHandle） */
static osThreadId_t g_ekf_task_handle  = NULL;
static osThreadId_t g_lora_task_handle = NULL;

/* P0-D：感測器健康監測（失流/卡死/範圍）。彙整位 SH_BIT_* 供 FSM/遙測/[HEALTH] 行。 */
static SensorMon_t g_mon_bmi088;
static SensorMon_t g_mon_adxl375;
static SensorMon_t g_mon_bmp388;
volatile uint8_t g_sensor_fault_bits = 0;
/* 落地時刻 tick（0 = 尚未落地）。SD 全程記錄據此由 100Hz 降為 10Hz，並於逾時後自動關檔 (Item E)。 */
volatile uint32_t g_touchdown_tick = 0;

BMI088_Data_t imu_data;
ADXL375_Data_t highg_data;
BMP388_Data_t baro_data;

uint8_t bmi088_ok = 0;
uint8_t adxl375_ok = 0;
uint8_t bmp388_ok = 0;
uint8_t mag_ok = 0;       /* MMC5983MA 地磁計（I2C1）初始化狀態 */
uint8_t lora433_ok = 0;   /* E22-400T30S 433MHz LoRa (UART3 透傳) 初始化狀態 */
uint8_t lora920_ok = 0;   /* E80-900M2213S 920MHz LoRa (SX126x SPI3) 初始化狀態 */

/* 命令台改 LoRa 參數期間 = 1：遙測任務跳過該槽不發射。保護兩件事：
 * ① E22 設定模式（M1=1）期間透傳資料衝進 UART3 會被模組當成設定命令（可能誤寫暫存器）；
 * ② E80 Reconfig 為多段 SPI 命令序列，不可與 LoRaE80_Send 交錯。 */
volatile uint8_t g_lora_cfg_pause = 0;

/* 硬鐵校正輔助：CMD_MAG_CAL_START/STOP 切換 [MAG] 印出頻率 1Hz<->50Hz。
 * 平常維持 1Hz（避免飛行遙測 UART 負載增加），校正時提速方便地面站工具
 * 快速收集足夠樣本（ground_station/tools/mag_calibrate.py）。 */
volatile uint8_t g_mag_cal_fast_print = 0;

/* 最新電池電壓 (mV)，由飛控迴圈讀 ADC 後更新；遙測與 [PWR] 行唯讀此值（避免 ADC 並發） */
volatile uint16_t g_bat_voltage_mv = 0;

/* SPI3 共用匯流排互斥鎖（W25Q128 Flash + E80 920MHz LoRa）。於 RTOS init 建立。 */
osMutexId_t g_spi3_mutex = NULL;
osMutexId_t g_uart_printf_mutex = NULL;

/* 採樣率監測器：在 IDE Watch / Live Expressions 加入《g_sampling_rate》即可一次觀察所有感測器 */
SAMPLING_RATE_DECL();   /* 展開為: SamplingRateAll_t g_sampling_rate */

/* --- EKF 1000 Hz Double Buffers in SRAM --- */
EKF_Buffer_t g_ekf_buffers[2];
volatile uint8_t g_ekf_active_idx = 0;
volatile uint8_t g_ekf_sample_count = 0;
/* EKF queue put 失敗計數：消費端 (EKF_Task) 落後造成 buffer 來不及入列時遞增。
 * 由 [RATE] 行輸出供觀測；若長期 >0 才需考慮擴大 buffer pool + queue 深度 (Item I)。 */
volatile uint32_t g_ekf_queue_drops = 0;

/* --- TIM3 (3.2 kHz) ADXL375 Ping-Pong 雙緩衝區宣告 --- */
#define ADXL_BATCH_SIZE 32
typedef struct {
    int16_t x_raw;
    int16_t y_raw;
    int16_t z_raw;
    float ax;
    float ay;
    float az;
} ADXL_Sample_t;

ADXL_Sample_t g_adxl_batches[2][ADXL_BATCH_SIZE];
volatile uint8_t g_adxl_active_batch = 0;   // 當前寫入的半區 (0 or 1)
volatile uint8_t g_adxl_sample_count = 0;   // 當前半區已累積的樣本數 (0..31)
volatile uint8_t g_adxl_new_batch_ready = 0;// 1 代表有一批 (32筆) 數據集滿
volatile uint8_t g_adxl_ready_batch_idx = 0;// 已集滿可讀取的半區索引

/* --- TIM6 (1.6 kHz) BMI088 Accel Ping-Pong 雙緩衝區宣告 --- */
#define BMI_ACC_BATCH_SIZE 16
typedef struct {
    int16_t accel_x_raw;
    int16_t accel_y_raw;
    int16_t accel_z_raw;
    float ax, ay, az;
} BMI_Accel_Sample_t;

BMI_Accel_Sample_t g_bmi_acc_batches[2][BMI_ACC_BATCH_SIZE];
volatile uint8_t g_bmi_acc_active_batch = 0;   // 當前寫入的半區 (0 or 1)
volatile uint8_t g_bmi_acc_sample_count = 0;   // 當前半區已累積的樣本數 (0..15)
volatile uint8_t g_bmi_acc_new_batch_ready = 0;// 1 代表有一批 (16筆) 數據集滿
volatile uint8_t g_bmi_acc_ready_batch_idx = 0;// 已集滿可讀取的半區索引

/* --- TIM7 (2.0 kHz) BMI088 Gyro Ping-Pong 雙緩衝區宣告 --- */
#define BMI_GYRO_BATCH_SIZE 20
typedef struct {
    int16_t gyro_x_raw;
    int16_t gyro_y_raw;
    int16_t gyro_z_raw;
    float gx, gy, gz;
} BMI_Gyro_Sample_t;

BMI_Gyro_Sample_t g_bmi_gyro_batches[2][BMI_GYRO_BATCH_SIZE];
volatile uint8_t g_bmi_gyro_active_batch = 0;   // 當前寫入的半區 (0 or 1)
volatile uint8_t g_bmi_gyro_sample_count = 0;   // 當前半區已累積的樣本數 (0..19)
volatile uint8_t g_bmi_gyro_new_batch_ready = 0;// 1 代表有一批 (20筆) 數據集滿
volatile uint8_t g_bmi_gyro_ready_batch_idx = 0;// 已集滿可讀取的半區索引
/* USER CODE END PV */

void SystemClock_Config(void);
static void MX_GPIO_Init(void);
static void MX_DMA_Init(void);
static void MX_I2C1_Init(void);
static void MX_SDIO_SD_Init(void);
static void MX_SPI1_Init(void);
static void MX_SPI2_Init(void);
static void MX_SPI3_Init(void);
static void MX_USART2_UART_Init(void);
static void MX_USART3_UART_Init(void);
static void MX_USART6_UART_Init(void);
static void MX_TIM4_Init(void);
static void Servo_HoldLow(void);   /* 主傘舵機 PD14 開機拉低（無 PWM 訊號），部署時才輸出 */
static void MX_ADC1_Init(void);
static void MX_IWDG_Init(void);
static void MX_RTC_Init(void);
static void MX_TIM2_Init(void);
static void MX_TIM3_Init(void);
static void MX_TIM6_Init(void);
static void MX_TIM7_Init(void);
#if !FEATURE_USB_CDC
static void MX_USB_OTG_FS_PCD_Init(void);
#endif
static void MX_CRC_Init(void);
static void MX_RNG_Init(void);
void StartDefaultTask(void *argument);

/* USER CODE BEGIN PFP */
uint16_t ADC_Read_Battery_mv(void);
void LoRaTelemetry_Task(void *argument);   /* 5Hz 下行遙測：E22(433) + E80(920) */
#ifdef ENABLE_DIAGNOSTICS
void StartDiagnosticTask(void *argument);
#endif
/* USER CODE END PFP */

/**
  * @brief  The application entry point.
  * @retval int
  */
int main(void)
{

  /* MCU Configuration--------------------------------------------------------*/

  /* Reset of all peripherals, Initializes the Flash interface and the Systick. */
  HAL_Init();

  /* USER CODE BEGIN Init */
  /* 擷取上一次重置原因（診斷「拔掉 UART 就一直重啟」）。RCC CSR 旗標跨重置保留至清除。 */
  uint32_t reset_csr = RCC->CSR;
  __HAL_RCC_CLEAR_RESET_FLAGS();
  /* USER CODE END Init */

  /* Configure the system clock */
  SystemClock_Config();

  /* Initialize all configured peripherals */
  MX_GPIO_Init();
  MX_DMA_Init();
  MX_I2C1_Init();
  MX_SDIO_SD_Init();
  MX_SPI1_Init();
  MX_SPI2_Init();
  MX_SPI3_Init();
  MX_USART2_UART_Init();
  MX_USART3_UART_Init();
  MX_USART6_UART_Init();
  MX_TIM4_Init();
  MX_ADC1_Init();
  MX_IWDG_Init();
  MX_RTC_Init();
  MX_TIM2_Init();
  MX_TIM3_Init();
  MX_TIM6_Init();
  MX_TIM7_Init();
#if !FEATURE_USB_CDC
  MX_USB_OTG_FS_PCD_Init();   /* 飛行版：低階 PCD；地面站改由 USB-CDC 的 usbd_conf 帶起 */
#endif
  MX_CRC_Init();
  MX_RNG_Init();
  MX_FATFS_Init();
  /* USER CODE BEGIN 2 */
  /* 主傘舵機 PD14 立即拉低：MX_TIM4_Init 的 MspPostInit 已把 PD14 設為 TIM4 AF，此處覆蓋為
   * GPIO 輸出並拉低，確保開機到部署前腳位「完全無訊號」（部署時 Servo_DeployMain 才切回 AF）。 */
  Servo_HoldLow();
  setvbuf(stdout, NULL, _IONBF, 0);   /* 關閉 stdout 緩衝，使所有 FreeRTOS 任務的 printf 立即送往 UART，防慢速任務因獨立 reent 結構積壓不印 */
  HAL_Delay(500);   /* 延遲 500ms 讓 USB-TTL 串口驅動在 MCU 重置後有時間穩定，防止 PC 端漏字 */
  /* 開機橫幅：版本 + 角色，重複三次（剛接上序列埠/雜訊環境也至少看得到一次）。 */
  {
      const char *role_str =
          IS_GROUND  ? "GROUND(地面站)" :
          IS_BACKUP  ? "BACKUP(備援)"   : "PRIMARY(主航電)";
      for (int v = 0; v < 3; v++) {
          printf("============================================================\r\n");
          printf("[BOOT] RocketCom FW=%s  ROLE=%s  (git=%s build=%s)\r\n",
                 FIRMWARE_VERSION, role_str, FW_GIT, FW_BUILD);
      }
      printf("============================================================\r\n");
  }
  /* 開機印出重置原因：POR/BOR=電源/欠壓(拔 UART 掉電/LoRa 發射突波最常見)；
   * IWDG=看門狗逾時(任務卡住)；SOFT=軟體重置；PIN=外部復位腳。 */
  printf("[RESET] %s%s%s%s%s%s%s(CSR=0x%08lX)\r\n",
         (reset_csr & RCC_CSR_BORRSTF)  ? "BOR(欠壓) "          : "",
         (reset_csr & RCC_CSR_PORRSTF)  ? "POR/PDR(上電/欠壓) " : "",
         (reset_csr & RCC_CSR_IWDGRSTF) ? "IWDG(看門狗) "       : "",
         (reset_csr & RCC_CSR_WWDGRSTF) ? "WWDG "               : "",
         (reset_csr & RCC_CSR_SFTRSTF)  ? "SOFT(軟體) "         : "",
         (reset_csr & RCC_CSR_LPWRRSTF) ? "LPWR "               : "",
         (reset_csr & RCC_CSR_PINRSTF)  ? "PIN(外部腳) "        : "",
         (unsigned long)reset_csr);
  fflush(stdout);
#if FEATURE_PYRO_SELFTEST
  /* === PYRO SELF-TEST（開傘 PWM 舵機台面自測）===
   * 每次重啟自動跑一次舵機釋放序列後停在原地（不進飛控 FSM）。
   * 飛行前務必在 board_config.h 把 FEATURE_PYRO_SELFTEST 設回 0。 */
  PyroSelfTest_RunOnce();   /* 不返回：停在無窮迴圈持續餵 IWDG */
#endif
#if FEATURE_USB_CDC
  MX_USB_DEVICE_Init();   /* 地面站：USB 虛擬序列埠 (CDC)。飛行版不啟用（不列舉、不佔 CPU）。 */
#endif
#if FEATURE_FLIGHT   /* 主/備：飛控感測器 (IMU/高G/氣壓)；地面站 (ROLE_GROUND) 不啟用以省資源 */
  float bmi_boot_ref_ax = 0.0f, bmi_boot_ref_ay = 0.0f, bmi_boot_ref_az = 1.0f;
  uint8_t bmi_boot_ref_valid = 0U;
  if (BMI088_Init(&hspi2) == HAL_OK) {
      bmi088_ok = 1;
      /* 先同步取樣 40 筆當 ADXL375 校正參考（須在 TIM6 中斷啟動「前」做，否則
       * 1.6kHz ISR 與本處主執行緒對同一顆 SPI2/BMI088 並發存取，無鎖保護）。 */
      {
          BMI088_Accel_t a;
          float sx = 0.0f, sy = 0.0f, sz = 0.0f;
          int n = 0;
          for (int k = 0; k < 40; k++) {
              if (BMI088_ReadAccel(&hspi2, &a) == HAL_OK) { sx += a.ax; sy += a.ay; sz += a.az; n++; }
              HAL_Delay(2);
          }
          if (n > 0) {
              bmi_boot_ref_ax = sx / (float)n;
              bmi_boot_ref_ay = sy / (float)n;
              bmi_boot_ref_az = sz / (float)n;
              bmi_boot_ref_valid = 1U;
          }
      }
      HAL_TIM_Base_Start_IT(&htim6);                           // 啟動 TIM6 1.6 kHz 中斷採樣 (Accel)
      HAL_TIM_Base_Start_IT(&htim7);                           // 啟動 TIM7 2.0 kHz 中斷採樣 (Gyro)
  }
  if (ADXL375_Init(&hspi1) == HAL_OK) {
      adxl375_ok = 1;
      ADXL375_DumpDiag(&hspi1);                                // 開機診斷：配置回讀 + raw hex（查偶數量化/無重力異常）
      if (bmi_boot_ref_valid) {
          /* 用 BMI088（乾淨、平放 σ=5mG）當參考，校正 ADXL375 零點偏移（封裝應力，
           * 實測平放 z 僅 20mG 應≈1000mG）。★兩顆晶片原生座標系不同（BMI088 晶片
           * Z 朝下、X/Y 對調；ADXL375 晶片 Z 朝上、X/Y 直接取負——見 sensor_axis.h
           * 與 tests/test_sensor_axis.c 的實體貼裝反推），不可直接拿 BMI 原生值當
           * ADXL 原生目標。由兩者 body-frame 映射消去 body 分量反推：
           *   adxl_target_x = -bmi_y, adxl_target_y = -bmi_x, adxl_target_z = -bmi_z */
          ADXL375_CalibrateAgainstRef(&hspi1, -bmi_boot_ref_ay, -bmi_boot_ref_ax, -bmi_boot_ref_az);
      }
      HAL_TIM_Base_Start_IT(&htim3);                           // 啟動 TIM3 3.2 kHz 中斷採樣
  }
  if (BMP388_Init(&hspi1, &baro_data) == HAL_OK) {
      bmp388_ok = 1;
      /* 以發射台環境溫度鎖定高度換算參考溫度 T0 (Item H)。
       * 取 16 筆讀數平均濾除單筆雜訊；必須在 EKF 校準（RTOS 啟動後）之前完成，
       * 使 launchpad 參考與飛行讀數共用同一 T0，相對高度於發射台恆為 0 且全程連續。
       * BMP388 與 ADXL375 共用 SPI1，讀取時暫關 TIM3 中斷以避免匯流排競爭（同主迴圈做法）。 */
      float t0_sum = 0.0f;
      int   t0_n   = 0;
      for (int i = 0; i < 16; i++) {
          __HAL_TIM_DISABLE_IT(&htim3, TIM_IT_UPDATE);
          HAL_StatusTypeDef t0_res = BMP388_ReadData(&hspi1, &baro_data);
          __HAL_TIM_ENABLE_IT(&htim3, TIM_IT_UPDATE);
          if (t0_res == HAL_OK) {
              t0_sum += baro_data.temperature;
              t0_n++;
          }
          HAL_Delay(5);   /* BMP388 200Hz ODR → 5ms 取得新樣本 */
      }
      if (t0_n > 0) {
          float t0_avg = t0_sum / (float)t0_n;
          BMP388_SetReferenceTemp(t0_avg);
          printf("[BMP388] 高度換算參考溫度 T0 鎖定為 %d.%02d °C\r\n",
                 (int)t0_avg,
                 (int)(fabsf(t0_avg - (int)t0_avg) * 100.0f));
      }
  }
#else
  bmi088_ok = 0;
  adxl375_ok = 0;
  bmp388_ok = 0;   /* 地面站：不啟用 IMU/高G/氣壓感測器 */
#endif /* FEATURE_FLIGHT */

  /* GPS 驅動啟動 (USART6, NMEA-0183, 循環 DMA + IDLE 接收)。
   * NEO-M9N 實體掛載於 USART6（PC6/PC7）；解析於 task context（主迴圈 GPS_Update()）進行，
   * ISR/DMA 事件回呼僅組句設旗標。 */
#if FEATURE_GPS
  GPS_Init(&huart6);
#endif

  /* MMC5983MA 三軸地磁計啟動 (I2C1, SCL=PB7/SDA=PB8, 位址 0x30)。
   * 初始化含 Product ID 驗證、軟體重置、400Hz 頻寬與一次 SET/RESET 橋偏校準。
   * 失敗（晶片未上線）僅記錄旗標，不阻擋系統啟動。 */
#if FEATURE_MAG
  if (MMC5983_Init() == HAL_OK) {
      mag_ok = 1;
      printf("[MAG] MMC5983MA online. offset[X,Y,Z]=%ld,%ld,%ld\r\n",
             (long)MMC5983_GetData()->offset[0],
             (long)MMC5983_GetData()->offset[1],
             (long)MMC5983_GetData()->offset[2]);
  } else {
      mag_ok = 0;
      printf("[MAG] MMC5983MA NOT detected (I2C1).\r\n");
  }
#else
  mag_ok = 0;   /* 備板：磁力計 (I2C1) 關閉 */
#endif

#if FEATURE_LORA
  /* E22-400T30S 433MHz LoRa 啟動（UART3 透傳模式 M0=M1=0）。
   * 重置 + 等 AUX 拉高；未接模組也不阻擋啟動（發送由 AUX 背壓守護）。
   * 地面站固定啟用（收 433 下行）；主航電由 LORA433_ENABLE 決定是否啟用 433。 */
#if IS_GROUND || LORA433_ENABLE
  lora433_ok = 0;
  for (int retry = 0; retry < 5; retry++) {
      HAL_IWDG_Refresh(&hiwdg);
      if (LoRaE22_Init(&huart3) == HAL_OK) {
          lora433_ok = 1;
          break;
      }
      HAL_Delay(150);
  }
  if (lora433_ok) {
      printf("[LORA433] E22 偵測成功（config 回讀 OK），透傳就緒 (UART3)。\r\n");
      LoRaE22_PrintConfig();
  } else {
      printf("[LORA433] ⚠ E22 未偵測到（config 無回應）—— 確認模組/接線/供電；主航電遙測任務每 10s 重試。\r\n");
  }
#if FEATURE_UPLINK_DEPLOY
  /* 主航電：在下行之外開啟 USART3 上行接收（地面站手動開傘命令）。
   * E22 透傳模式不發送時即在接收；遙測任務每 10 槽空出 1 槽不發 433 留給上行。 */
  UplinkCmd_Init();
#endif
#else
  lora433_ok = 0;
  printf("[LORA433] disabled (LORA433_ENABLE=0) — 433 下行停用，UART3 不發送。\r\n");
#endif

  HAL_IWDG_Refresh(&hiwdg);

  /* E80-900M2213S 920MHz LoRa 啟動（SX126x/LLCC68, SPI3，與 Flash 共用匯流排）。 */
#if IS_GROUND
  lora920_ok = 0;
  for (int retry = 0; retry < 5; retry++) {
      HAL_IWDG_Refresh(&hiwdg);
      if (LoRaE80_Init(&hspi3) == HAL_OK && LoRaE80_StartRx() == HAL_OK) {
          lora920_ok = 1;
          break;
      }
      HAL_Delay(150);
  }
  if (lora920_ok) {
      printf("[LORA920] E80 RX online (SX126x SPI3, continuous RX).\r\n");
  } else {
      LoRaE80_Shutdown();
      printf("[LORA920] E80 RX init failed — held in reset (SPI3 freed for Flash).\r\n");
  }
#elif LORA920_ENABLE
  lora920_ok = 0;
  for (int retry = 0; retry < 5; retry++) {
      HAL_IWDG_Refresh(&hiwdg);
      if (LoRaE80_Init(&hspi3) == HAL_OK) {
          lora920_ok = 1;
          break;
      }
      HAL_Delay(150);
  }
  if (lora920_ok) {
      /* Init 已完成全部 RF 設定（standby_rc → RF 開關 → LoRa 封包型態 → HP PA/VBAT →
       * 920MHz/SF9/BW250/CR4-5/+22dBm → 封包參數 → sync word → TxDone IRQ）。
       * 不再啟動連續載波(CW)；E80 留在 standby，由 LoRaTelemetry_Task 每包脈衝 SetTx 發送下行。 */
      printf("[LORA920] E80 online (LR1121 SPI3) — standby，下行由遙測任務每包脈衝發送。\r\n");
  } else {
      LoRaE80_Shutdown();   /* 偵測失敗（含 MISO 接地/浮空）→ RST 拉低隔離，釋放 SPI3 */
      printf("[LORA920] E80 NOT detected — held in reset to free SPI3 (protect Flash).\r\n");
  }
#else
  lora920_ok = 0;
  LoRaE80_Shutdown();       /* 主動停用：RST 拉低使 E80 不驅動共用 SPI3 MISO */
  printf("[LORA920] disabled (LORA920_ENABLE=0) — held in reset, SPI3 freed for Flash.\r\n");
#endif
#else  /* !FEATURE_LORA（備援航電）：不啟用任何 LoRa；仍按住 E80 RST 保護 SPI3 上的 Flash */
  lora433_ok = 0;
  lora920_ok = 0;
  LoRaE80_Shutdown();       /* RST 拉低使 E80 不驅動共用 SPI3 MISO（飛行資料記錄保護） */
#endif
  /* E22(最壞 900ms) + E80(最壞 560ms) 合計可達 ~1.5s；補餵一次防 IWDG 2.05s 到期。
   * Flash_Test() 含 sector erase(400ms) + write(500ms) 再補一次。 */
  HAL_IWDG_Refresh(&hiwdg);

#if FEATURE_FLASH
  /* W25Qxx SPI Flash 啟動自檢 (SPI3, CS=PA15) */
  Flash_Test();
  HAL_IWDG_Refresh(&hiwdg);
#endif

  /* Buzzer 開機提示音：依角色不同節奏，耳朵即可確認「燒對角色」（呼應 board_config 角色易混）。
   * TIM2 時基 1MHz → 頻率 = 1e6/(ARR+1)。所有角色都會響（TIM2 與此段皆無條件執行）。 */
#if FEATURE_BUZZER
  HAL_TIM_PWM_Start(&htim2, TIM_CHANNEL_1);
#if IS_GROUND
  for (int b = 0; b < 3; b++) {                 /* 地面站：三短聲 2kHz */
      htim2.Instance->ARR = 499; htim2.Instance->CCR1 = 250; htim2.Instance->EGR = TIM_EGR_UG;
      HAL_Delay(90);
      htim2.Instance->CCR1 = 0;
      HAL_Delay(90);
  }
#elif IS_BACKUP
  htim2.Instance->ARR = 499; htim2.Instance->CCR1 = 250; htim2.Instance->EGR = TIM_EGR_UG;  /* 備援：一長聲 2kHz */
  HAL_Delay(500);
  htim2.Instance->CCR1 = 0;
#else                                            /* 主航電：兩聲漸高 2kHz→4kHz */
  htim2.Instance->ARR = 499; htim2.Instance->CCR1 = 250; htim2.Instance->EGR = TIM_EGR_UG;
  HAL_Delay(100);
  htim2.Instance->CCR1 = 0;
  HAL_Delay(100);
  htim2.Instance->ARR = 249; htim2.Instance->CCR1 = 125; htim2.Instance->EGR = TIM_EGR_UG;
  HAL_Delay(100);
  htim2.Instance->CCR1 = 0;
#endif
  HAL_IWDG_Refresh(&hiwdg);   /* 提示音占用 ~0.4–0.5s，補餵一次防 IWDG */
#endif
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

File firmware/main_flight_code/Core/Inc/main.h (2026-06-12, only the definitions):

#define LED_SYS_Pin GPIO_PIN_2
#define LED_SYS_GPIO_Port GPIOE
#define LED_STAT2_Pin GPIO_PIN_4
#define LED_STAT2_GPIO_Port GPIOE
#define BAT_SENSE_Pin GPIO_PIN_0
#define BAT_SENSE_GPIO_Port GPIOC
#define USER_BT2_Pin GPIO_PIN_3
#define USER_BT2_GPIO_Port GPIOC
#define USER_BT1_Pin GPIO_PIN_1
#define USER_BT1_GPIO_Port GPIOA
#define CSB_BARO_Pin GPIO_PIN_4
#define CSB_BARO_GPIO_Port GPIOA
#define CSB_HIGHG_Pin GPIO_PIN_4
#define CSB_HIGHG_GPIO_Port GPIOC
#define INT_HIGHG2_Pin GPIO_PIN_5
#define INT_HIGHG2_GPIO_Port GPIOC
#define INT_HIGHG2_EXTI_IRQn EXTI9_5_IRQn
#define INT_HIGHG1_Pin GPIO_PIN_0
#define INT_HIGHG1_GPIO_Port GPIOB
#define INT_BARO_Pin GPIO_PIN_1
#define INT_BARO_GPIO_Port GPIOB
#define INT_ACCEL1_Pin GPIO_PIN_7
#define INT_ACCEL1_GPIO_Port GPIOE
#define INT_ACCEL1_EXTI_IRQn EXTI9_5_IRQn
#define INT_ACCEL2_Pin GPIO_PIN_8
#define INT_ACCEL2_GPIO_Port GPIOE
#define INT_ACCEL2_EXTI_IRQn EXTI9_5_IRQn
#define INT_GYRO1_Pin GPIO_PIN_9
#define INT_GYRO1_GPIO_Port GPIOE
#define INT_GYRO1_EXTI_IRQn EXTI9_5_IRQn
#define INT_GYRO2_Pin GPIO_PIN_10
#define INT_GYRO2_GPIO_Port GPIOE
#define INT_GYRO2_EXTI_IRQn EXTI15_10_IRQn
#define LORA433_BUSY_Pin GPIO_PIN_11
#define LORA433_BUSY_GPIO_Port GPIOE
#define INT_MAGN_Pin GPIO_PIN_12
#define INT_MAGN_GPIO_Port GPIOE
#define INT_MAGN_EXTI_IRQn EXTI15_10_IRQn
#define CSB_GYRO_Pin GPIO_PIN_11
#define CSB_GYRO_GPIO_Port GPIOB
#define CSB_ACCEL_Pin GPIO_PIN_12
#define CSB_ACCEL_GPIO_Port GPIOB
#define LORA433_M1_Pin GPIO_PIN_10
#define LORA433_M1_GPIO_Port GPIOD
#define LORA433_M0_Pin GPIO_PIN_11
#define LORA433_M0_GPIO_Port GPIOD
#define LORA433_RST_Pin GPIO_PIN_12
#define LORA433_RST_GPIO_Port GPIOD
#define FIRE_Pin GPIO_PIN_13
#define FIRE_GPIO_Port GPIOD
#define PWM_Servo_Pin GPIO_PIN_14
#define PWM_Servo_GPIO_Port GPIOD
#define RST_GPS_Pin GPIO_PIN_8
#define RST_GPS_GPIO_Port GPIOA
#define FLASH_CSB_Pin GPIO_PIN_15
#define FLASH_CSB_GPIO_Port GPIOA
#define SDIO_DET_Pin GPIO_PIN_3
#define SDIO_DET_GPIO_Port GPIOD
#define LORA920_INT_Pin GPIO_PIN_4
#define LORA920_INT_GPIO_Port GPIOD
#define LORA920_INT_EXTI_IRQn EXTI4_IRQn
#define LORA920_RST_Pin GPIO_PIN_5
#define LORA920_RST_GPIO_Port GPIOD
#define LORA920_BUSY_Pin GPIO_PIN_6
#define LORA920_BUSY_GPIO_Port GPIOD
#define LORA920_BUSY_EXTI_IRQn EXTI9_5_IRQn
#define CSB_LORA920_Pin GPIO_PIN_7
#define CSB_LORA920_GPIO_Port GPIOD
#define SD_LANDED_LOG_TIMEOUT_MS 1800000UL  // 落地後 SD 持續記錄上限 (30 分鐘)，逾時自動關檔

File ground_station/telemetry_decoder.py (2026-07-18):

#!/usr/bin/env python3
# -*- coding: utf-8 -*-
"""
telemetry_decoder.py — RocketCom 下行遙測二進制解碼器（地面站）

封包契約（與 Main_Code/Core/Inc/telemetry.h 同步,由 tests/test_telemetry.c 機器鎖定）:
    79 bytes packed little-endian, sync 0xA5,0x5A,
    CRC-16/CCITT-FALSE (poly=0x1021, init=0xFFFF) 覆蓋前 77 bytes。

用法:
    python3 telemetry_decoder.py --port /dev/cu.usbserial-110 --baud 460800
    python3 telemetry_decoder.py --file dump.bin
    python3 telemetry_decoder.py --file dump.bin --csv out.csv
    python3 telemetry_decoder.py --selftest

來源可以是 E22 433MHz 透傳接收端 UART、E80 920MHz 接收端,或任何含封包流的檔案。
逐位元組掃描 sync 對齊,CRC 失敗自動滑動重同步;統計丟包(seq gap)與 CRC 錯誤。
"""
import argparse
import struct
import sys
import time

PACKET_SIZE = 79
SYNC0, SYNC1 = 0xA5, 0x5A

# 與 test_telemetry.c offset 表一一對應(little-endian)
_STRUCT_FMT = "<4BI2i4hiI12h2ih2B3H3BH"
_FIELDS = [
    "sync0", "sync1", "seq", "fsm_state", "tick_ms",
    "ekf_pos_z_cm", "ekf_vel_z_cms",
    "ekf_q0", "ekf_q1", "ekf_q2", "ekf_q3",
    "baro_alt_cm", "baro_press_pa",
    "imu_ax_mg", "imu_ay_mg", "imu_az_mg",
    "gyro_x_dps", "gyro_y_dps", "gyro_z_dps",
    "hg_ax_cg", "hg_ay_cg", "hg_az_cg",
    "mag_x_mg", "mag_y_mg", "mag_z_mg",
    "gps_lat_1e6", "gps_lon_1e6", "gps_alt_m", "gps_sats", "gps_fix",
    "bat_mv", "cpu_main_x10", "cpu_ekf_x10",
    "flags", "health_bits", "sensor_bits", "crc16",
]
assert struct.calcsize(_STRUCT_FMT) == PACKET_SIZE, struct.calcsize(_STRUCT_FMT)
assert len(_FIELDS) == len(_STRUCT_FMT.replace("<", "").replace("4B", "BBBB")
                           .replace("2i", "ii").replace("4h", "hhhh")
                           .replace("12h", "h" * 12).replace("2h", "hh")
                           .replace("2B", "BB").replace("3H", "HHH")
                           .replace("3B", "BBB"))

FSM_NAMES = ["INIT", "PAD", "BOOST", "COAST", "DEPLOY_DROGUE", "APOGEE", "DESCENT", "MAIN", "LANDED"]
FLAG_NAMES = [
    (0x01, "DROGUE"), (0x02, "MAIN"), (0x04, "SD"), (0x08, "GPS_STALE"),
    (0x10, "EKF_UNHEALTHY"), (0x20, "SENSOR_FAULT"), (0x40, "FAILSAFE"), (0x80, "HOTSTART"),
]


def crc16_ccitt_false(data: bytes) -> int:
    crc = 0xFFFF
    for byte in data:
        crc ^= byte << 8
        for _ in range(8):
            crc = ((crc << 1) ^ 0x1021) & 0xFFFF if (crc & 0x8000) else (crc << 1) & 0xFFFF
    return crc


class Stats:
    def __init__(self):
        self.ok = 0
        self.crc_err = 0
        self.lost = 0
        self.last_seq = None

    def feed_seq(self, seq: int):
        if self.last_seq is not None:
            gap = (seq - self.last_seq - 1) & 0xFF
            self.lost += gap
        self.last_seq = seq

    def summary(self) -> str:
        total = self.ok + self.lost
        rate = (100.0 * self.lost / total) if total else 0.0
        return f"封包 OK={self.ok}  丟包={self.lost} ({rate:.1f}%)  CRC錯誤={self.crc_err}"


def decode_packet(raw: bytes) -> dict:
    vals = struct.unpack(_STRUCT_FMT, raw)
    return dict(zip(_FIELDS, vals))


def fmt_human(p: dict) -> str:
    fsm = FSM_NAMES[p["fsm_state"]] if p["fsm_state"] < len(FSM_NAMES) else f"?{p['fsm_state']}"
    flags = "|".join(name for bit, name in FLAG_NAMES if p["flags"] & bit) or "-"
    gps = (f"{p['gps_lat_1e6']/1e6:.6f},{p['gps_lon_1e6']/1e6:.6f} alt={p['gps_alt_m']}m "
           f"sats={p['gps_sats']}" if p["gps_fix"] else "no-fix")
    health = ""
    if p["health_bits"] or p["sensor_bits"]:
        health = f" !ekf=0x{p['health_bits']:02X} !sens=0x{p['sensor_bits']:02X}"
    return (f"#{p['seq']:3d} t={p['tick_ms']/1000.0:8.2f}s {fsm:7s} "
            f"h={p['ekf_pos_z_cm']/100.0:7.2f}m v={p['ekf_vel_z_cms']/100.0:7.2f}m/s "
            f"baro={p['baro_alt_cm']/100.0:8.2f}m bat={p['bat_mv']/1000.0:.2f}V "
            f"[{flags}]{health} gps={gps}")


def csv_header() -> str:
    return ",".join(_FIELDS[2:])  # 跳過 sync bytes


def fmt_csv(p: dict) -> str:
    return ",".join(str(p[f]) for f in _FIELDS[2:])


def scan_stream(read_chunk, stats: Stats, on_packet):
    """read_chunk() → bytes(可空)；逐位元組掃 sync,CRC 過才算封包,失敗滑動 1 byte 重同步。"""
    buf = bytearray()
    while True:
        chunk = read_chunk()
        if chunk is None:
            break
        buf.extend(chunk)
        while len(buf) >= PACKET_SIZE:
            if buf[0] != SYNC0 or buf[1] != SYNC1:
                del buf[0]
                continue
            raw = bytes(buf[:PACKET_SIZE])
            crc_recv = raw[77] | (raw[78] << 8)
            if crc16_ccitt_false(raw[:77]) != crc_recv:
                stats.crc_err += 1
                del buf[0]      # 滑動重同步(可能是假 sync 或封包損毀)
                continue
            p = decode_packet(raw)
            stats.ok += 1
            stats.feed_seq(p["seq"])
            on_packet(p)
            del buf[:PACKET_SIZE]


def make_selftest_packet(seq=7) -> bytes:
    vals = {f: 0 for f in _FIELDS}
    vals.update(sync0=SYNC0, sync1=SYNC1, seq=seq, fsm_state=3, tick_ms=123456,
                ekf_pos_z_cm=25032, ekf_vel_z_cms=-1500, baro_alt_cm=24890,
                baro_press_pa=98412, bat_mv=11850, flags=0x41,
                health_bits=0x01, sensor_bits=0x04, gps_fix=0)
    raw = struct.pack(_STRUCT_FMT, *[vals[f] for f in _FIELDS])
    raw = raw[:77] + struct.pack("<H", crc16_ccitt_false(raw[:77]))
    return raw
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

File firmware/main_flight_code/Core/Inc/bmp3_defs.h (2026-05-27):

/**
* Copyright (c) 2022 Bosch Sensortec GmbH. All rights reserved.
*
* BSD-3-Clause
*
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
* 1. Redistributions of source code must retain the above copyright
*    notice, this list of conditions and the following disclaimer.
*
* 2. Redistributions in binary form must reproduce the above copyright
*    notice, this list of conditions and the following disclaimer in the
*    documentation and/or other materials provided with the distribution.
*
* 3. Neither the name of the copyright holder nor the names of its
*    contributors may be used to endorse or promote products derived from
*    this software without specific prior written permission.
*
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
* @file       bmp3_defs.h
* @date       2022-04-01
* @version    v2.0.6
*
*/

/*! @file bmp3_defs.h
 * @brief Sensor driver for BMP3 sensor */

#ifndef BMP3_DEFS_H_
#define BMP3_DEFS_H_

#define BMP3_FLOAT_COMPENSATION

/*! CPP guard */
#ifdef __cplusplus
extern "C" {
#endif

/********************************************************/
/* header includes */
#ifdef __KERNEL__
#include <linux/types.h>
#include <linux/kernel.h>
#else
#include <stdint.h>
#include <stddef.h>
#endif

/*************************** Common macros   *****************************/

#if !defined(UINT8_C) && !defined(INT8_C)
#define INT8_C(x)    S8_C(x)
#define UINT8_C(x)   U8_C(x)
#endif

#if !defined(UINT16_C) && !defined(INT16_C)
#define INT16_C(x)   S16_C(x)
#define UINT16_C(x)  U16_C(x)
#endif

#if !defined(INT32_C) && !defined(UINT32_C)
#define INT32_C(x)   S32_C(x)
#define UINT32_C(x)  U32_C(x)
#endif

#if !defined(INT64_C) && !defined(UINT64_C)
#define INT64_C(x)   S64_C(x)
#define UINT64_C(x)  U64_C(x)
#endif

/**@}*/
/**\name C standard macros */
#ifndef NULL
#ifdef __cplusplus
#define NULL         0
#else
#define NULL         ((void *) 0)
#endif
#endif

#ifndef TRUE
#define TRUE         UINT8_C(1)
#endif

#ifndef FALSE
#define FALSE        UINT8_C(0)
#endif

/********************************************************/
/**\name Compiler switch macros */

#ifndef BMP3_64BIT_COMPENSATION /*< Check if 64bit (using BMP3_64BIT_COMPENSATION) is enabled */
#ifndef BMP3_FLOAT_COMPENSATION /*< If 64 bit integer data type is not enabled then enable
                                            * BMP3_FLOAT_COMPENSATION */
#define BMP3_FLOAT_COMPENSATION
#endif
#endif

/********************************************************/
/**\name Macro definitions */

/**
 * BMP3_INTF_RET_TYPE is the read/write interface return type which can be overwritten by the build system.
 */
#ifndef BMP3_INTF_RET_TYPE
#define BMP3_INTF_RET_TYPE                      int8_t
#endif

/**
 * The last error code from read/write interface is stored in the device structure as intf_rslt.
 */
#ifndef BMP3_INTF_RET_SUCCESS
#define BMP3_INTF_RET_SUCCESS                   INT8_C(0)
#endif

/**\name I2C addresses */
#define BMP3_ADDR_I2C_PRIM                      UINT8_C(0x76)
#define BMP3_ADDR_I2C_SEC                       UINT8_C(0x77)

/**\name BMP3 chip identifier */
#define BMP3_CHIP_ID                            UINT8_C(0x50)
#define BMP390_CHIP_ID                          UINT8_C(0x60)

/**\name BMP3 pressure settling time (micro secs)*/
#define BMP3_SETTLE_TIME_PRESS                  UINT16_C(392)

/**\name BMP3 temperature settling time (micro secs) */
#define BMP3_SETTLE_TIME_TEMP                   UINT16_C(313)

/**\name BMP3 adc conversion time (micro secs) */
#define BMP3_ADC_CONV_TIME                      UINT16_C(2000)

/**\name Register Address */
#define BMP3_REG_CHIP_ID                        UINT8_C(0x00)
#define BMP3_REG_ERR                            UINT8_C(0x02)
#define BMP3_REG_SENS_STATUS                    UINT8_C(0x03)
#define BMP3_REG_DATA                           UINT8_C(0x04)
#define BMP3_REG_EVENT                          UINT8_C(0x10)
#define BMP3_REG_INT_STATUS                     UINT8_C(0x11)
#define BMP3_REG_FIFO_LENGTH                    UINT8_C(0x12)
#define BMP3_REG_FIFO_DATA                      UINT8_C(0x14)
#define BMP3_REG_FIFO_WM                        UINT8_C(0x15)
#define BMP3_REG_FIFO_CONFIG_1                  UINT8_C(0x17)
#define BMP3_REG_FIFO_CONFIG_2                  UINT8_C(0x18)
#define BMP3_REG_INT_CTRL                       UINT8_C(0x19)
#define BMP3_REG_IF_CONF                        UINT8_C(0x1A)
#define BMP3_REG_PWR_CTRL                       UINT8_C(0x1B)
#define BMP3_REG_OSR                            UINT8_C(0X1C)
#define BMP3_REG_ODR                            UINT8_C(0x1D)
#define BMP3_REG_CONFIG                         UINT8_C(0x1F)
#define BMP3_REG_CALIB_DATA                     UINT8_C(0x31)
#define BMP3_REG_CMD                            UINT8_C(0x7E)

/**\name Error status macros */
#define BMP3_ERR_FATAL                          UINT8_C(0x01)
#define BMP3_ERR_CMD                            UINT8_C(0x02)
#define BMP3_ERR_CONF                           UINT8_C(0x04)
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

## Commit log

2026-01-18 完成基本開機電路
    [SmallAvionic.kicad_sch]
2026-01-19 進度到usb
    [SmallAvionic.kicad_sch]
2026-01-20 Ray finish IMU,BMP, Madnetometer. But just whatever3 7 21 copy from internet
    [Ray.kicad_sch]
2026-01-22 Joyce push 1/22
    [Joyce.kicad_sch]
2026-02-01 complete small av,parachute board
    [Deployment board.kicad_pcb, Deployment board.kicad_sch, SmallAvionic.kicad_sch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]
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2026-02-04 Ray finish Ground Station Schematic
    [GroundStation.kicad_pcb, GroundStation.kicad_sch, Ray.kicad_sch]
2026-02-04 add little thing to Ground sch
    [GroundStation.kicad_sch]
2026-02-05 add little
    [GroundStation.kicad_sch]
2026-02-05 finished sensors except gps
    [Deployment board.kicad_sch, Iusbubula_Avionic_Board.kicad_sch, LoRa1E80-990M2213S.kicad_sch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]
2026-02-05 finished GPS
    [Iusbubula_Avionic_Board.kicad_sch]
2026-02-06 finish big av v1
    [Iusbubula_Avionic_Board.kicad_sch]
2026-02-06 GPS_Ground Revise
    [GroundStation.kicad_sch]
2026-03-08 assign package for groundstation
    [GroundStation.kicad_pcb, GroundStation.kicad_sch]
2026-03-12 Ray revise two LoRamodule, need Joyce help for free routing
    [GroundStation.kicad_sch, freerouting.dsn, temp-freerouting.dsn]
2026-03-15 finish first layer of big av
    [ADXL375BCCZ.kicad_sch, BMI008.kicad_sch, BMP390.kicad_sch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]
2026-03-20 adjust top layer wiring
    [Iusbubula_Avionic_Board.kicad_sch, Second_layer_MCU.kicad_pcb, Second_layer_MCU.kicad_sch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]
2026-03-23 jpush deployment board
    [Deployment board.kicad_pcb, Deployment board.kicad_sch]
2026-04-29 deployment board
    [Deployment board.kicad_sch, bom-JLCPCB Assembly Order (2).xls]
2026-05-03 recommit production
    [power layer.kicad_pcb]
2026-05-25 Update BigAvionic design and production files
    [Production_MCU_LORA_2_in_1-B_Cu.gbl, Production_MCU_LORA_2_in_1-B_Mask.gbs, Production_MCU_LORA_2_in_1-B_Paste.gbp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]
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2026-05-25 Update project progress (進度.md), rename Production_MCU_LORA_2_in_1 to Production_MCU_TOP_2_in_1, and restructure subprojects
    [Production_MCU_LORA_2_in_1-B_Cu.gbl, Production_MCU_LORA_2_in_1-B_Mask.gbs, Production_MCU_LORA_2_in_1-B_Paste.gbp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]
2026-05-25 Add Arduino GPS & Magnetometer test code and update project milestones in progress.md
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2026-05-25 Update hardware specs table to use STM32F407VGT6 and BMP388 due to component shortages, and update development progress
2026-05-25 add cad for cad
    [.step, body.SLDPRT, bottom.SLDPRT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]
2026-05-25 fix: rewrite 進度.md with clean UTF-8 to fix garbled text on GitHub
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2026-05-26 feat: 完成 MMC5983MA 驅動 bring-up 與 LED 感測器除錯
    目前 STM32 自製 PCB 的 bring-up 狀態：
    * GPS UART 驅動 bring-up 失敗
    * MMC5983MA 磁力計驅動 bring-up 成功
    * I2C 通訊已驗證成功
    * 已可週期性讀取磁力計 raw data
    * 建立 LED-only 感測器除錯流程
    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
2026-05-26 feat: add printf serial redirect to USART2 for real-time IMU wave plotting
2026-05-27 feat: stabilize NEO-M9N UART bring-up and LED-only GPS debug flow
    成功完成：
    * NEO-M9N GPS UART bring-up
    * USART1 interrupt receive 驗證
    * LED-only GPS alive debug
    * GPS UART RX path 穩定運作
    目前結果：
    * GPS UART RX 可穩定收到資料
    * LED 進入穩定慢閃狀態
    * 表示 `gps_rx_byte_count` 持續增加
    * USART1 RX interrupt path 已確認正常
    ---
    目前 LED 行為：
    * GPS UART RX 正常：
    LED 每秒慢閃一次
    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
    [gps.c, main.c]
2026-05-27 refactor: 模組化 GPS 與 MMC5983MA driver，為未來 F407 移植做準備
    將 GPS 與 MMC5983MA driver 從「能運作的測試碼」整理成「可移植的 HAL-based 模組」。
    目標：
    * 未來可從 STM32F103C8T6 移植到 STM32F407
    * 保持 driver 架構簡潔
    * 建立 raw data pipeline
    * 分離 driver 與 parser
    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
2026-05-27 feat: Flash ring buffer, SD card fixes, and rate monitor warm-up correction
    - Implement FlashRing_Init() with binary search resume and 10-sector pre-erase
    - Implement FlashRing_WritePacket() with CRC-16/CCITT, magic bytes, rolling erase
    - Fix SD card f_mount to immediate mode (opt=1) to resolve FR_NOT_READY on f_stat
    - Fix SD card filename auto-increment: HIL_001.CSV → HIL_002.CSV etc.
    - Reset SAMPLING_RATE_INIT() after FlashRing_Init() to eliminate BMP388 warm-up
    under-counting caused by 2s blocking pre-erase at boot
    - Add all new sensor drivers: adxl375, bmp388, w25qxx, rate_monitor
    - Add HIL test runner script (test_runner.py) with Flash ring buffer assertions
    - Update 進度.md with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
    [Main_AV_F407.ioc, adxl375.c, bmi088.c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]
2026-05-28 avionic bay v0
    [5.8Ghz video transmission system.step.STEP, AMASS_XT60-M_1x02_P7.2mm_Vertical.step.STEP, Bosch_LGA-8_2x2.5mm_P0.65mm_ClockwisePinNumbering.step.STEP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]
2026-06-01 docs: update 進度.md with git branch nodes, buzzer milestone, and improvement plan
    - add "目前 Git 分支節點" table (EKF_test / main / rayBranch)
    - record buzzer startup-beep milestone and TIM2 32-bit ARR overflow fix
    - add SD full-flight FSM-driven logging to phase-3 backlog
    - fix stale comment in main.c: W25Q128 Flash is on SPI3, not SPI1
    [main.c]
2026-06-01 feat(avionics): add EKF queue drop counter and gate boot flash-dump behind USER_BT1
    Low-risk subset of the improvement plan:
    - I (partial): count xEKFQueue put failures in g_ekf_queue_drops, report via
    [RATE] EKF_DROP. Defer the queue/buffer enlargement -- the queue carries
    pointers into a 2-slot ping-pong pool, and bss is already ~113KB/128KB, so a
    naive resize to 8 would overflow SRAM and risk stale-pointer overwrites.
    Instrument first, resize only if drops are observed.
    - N: Flash_DumpAll now runs only when USER_BT1 is held at boot, saving ~3-5s on
    normal startup (full flash dump otherwise runs every boot).
    - D: verified FPU context save is correct on ARM_CM4F (hard-float ABI,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
    [main.c]
2026-06-01 feat(avionics): replace 10s SD log cap with FSM-driven full-flight logging
    SD logging previously stopped after the first 10 seconds, so the entire
    flight (boost → apogee → descent → landing) was never captured. Replace
    that fixed window with FSM-driven full-flight logging:
    - Log at 100Hz from STATE_PAD through descent; drop to 10Hz after
    touchdown (new g_touchdown_tick marker — touchdown is a sub-condition
    inside STATE_LANDED, not its entry point).
    - Stop + safe-close on USER_BT1 press or SD_LANDED_LOG_TIMEOUT_MS
    (default 30 min) after touchdown.
    - Add fsm / ekf_alt_cm / ekf_vel_cms columns to the CSV header and rows.
    - f_sync once per second to bound data loss on power cut.
    -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
    [main.c, main.h]
2026-06-01 feat(baro): temperature-compensate altitude via launchpad-latched T0
    The altitude conversion used the ISA fixed-temperature barometric formula
    (44330*(1-(P/P0)^0.190295)), which assumes a 15C sea-level temperature and
    therefore mis-scales altitude by several percent in hot/cold conditions —
    biasing apogee height, derived velocity, and the main-deploy trigger.
    Replace it with the hypsometric (isothermal-layer) formula
    h = (R/g)*T0*ln(P0/P), and latch T0 from the actual launchpad temperature:
    - bmp388.c: add BMP388_SetReferenceTemp(temp_c) latching bmp388_ref_temp_K
    (default 288.15K = ISA, range-checked -40..85C). Altitude now scales with
    the latched T0.
    - main.c: right after BMP388 se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
    [bmp388.c, main.c]
2026-06-01 docs: add A+B (ADXL375 EKF fusion / SPI1 concurrency) bench design note
    Design + code sketch (no flight-code changes) for the two flight-critical
    improvement items, to be implemented in a hardware-in-the-loop session.
    Key finding documented as a blocking prerequisite for A: the EKF accel
    pipeline mixes units. BMI088 samples are in g (bmi088.c:162, x24/32768) but
    EKF_Predict (ekf.c:202) subtracts GRAVITY=9.80665 m/s2 and integrates as
    m/s2. Static calibration forces cancellation at rest (so ZUPT/bench static
    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
2026-06-01 feat(gps): add USART6 NMEA-0183 driver with DMA-to-idle RX
    Self-contained NMEA parser (gps.c/gps.h): GGA (fix quality/sats/
    altitude) and RMC (position/speed/course/validity), XOR checksum,
    manual ddmm.mmmm->deg*1e6 scaling, knots->m/s, talker-ID-agnostic
    sentence matching. Parsing runs in task context via GPS_Update();
    RX uses USART6 circular DMA + IDLE-line (HAL_UARTEx_ReceiveToIdle_DMA)
    with old_pos-diff byte extraction in the event callback (ISR-safe,
    no FreeRTOS calls). 256B DMA buffer verified in main SRAM (0x20000150,
    DMA2-accessible, not CCM). ErrorCallback restarts DMA RX on overrun.
    Integration: valid fixes fill the Flash ring-buffer gps_lat/gps_lon
    (previously hardcoded 0); new 1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
    [gps.c, main.c]
2026-06-01 docs: backfill GPS driver commit hash in 進度.md ledger
    Record 8c195cb against improvement item #4-J in the session block.
2026-06-02 feat(mag): add MMC5983MA magnetometer driver on I2C1
    18-bit one-shot driver for the MMC5983MA (I2C1, addr 0x30, SCL=PB7/SDA=PB8).
    Init verifies Product ID, software-resets, sets 400Hz bandwidth, and runs an
    initial SET/RESET bridge-offset calibration; MMC5983_Read() does a single TM_M
    measurement and subtracts the stored offset to output Gauss. Periodic
    MMC5983_Recalibrate() compensates thermal drift (skipped in flight).
    Wired into main.c: init after GPS (graceful skip if absent), 10Hz read +
    10s recalibration in the main loop, and 1Hz [MAG] telemetry. No EKF fusion
    yet — driver only logs the field vector for now.
    [main.c]
2026-06-02 feat(ekf): fuse GPS horizontal position (East/North) into EKF
    Add EKF_SubmitGPS(lat,lon,sats): after stationary calibration, the first valid
    fix latches the launchpad lat/lon origin; subsequent fixes are equirectangular-
    projected to ENU metres and published as a pending measurement. EKF_Task applies
    it once per buffer as two scalar Joseph-form updates on East/North (altitude is
    left to the far-more-accurate barometer). Measurement noise R scales with
    satellite count. GPS is only fused in flight — on the pad the ZUPT lock zeroes
    horizontal state, so pad-time fixes are dropped. main.c submits a fix only when
    last_fix_tick advances, avoiding 1kHz re-submission of the same NMEA fix.
    Co-Autho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
    [ekf.c, main.c]
2026-06-02 feat(ekf): fuse magnetometer heading (yaw) on the launchpad
    Add EKF_SubmitMag(mx,my,mz) + EKF_MagYawUpdate: a Mahony-style, tilt-compensated
    heading correction in the same body->nav rotation convention as the existing
    attitude filter. The reference field's horizontal magnitude is collapsed onto
    nav-East so the correction constrains yaw only, leaving roll/pitch to the gravity
    feedback. Applied once per buffer and ONLY on the pad (calibrated && !in_flight),
    to pin absolute heading and arrest the gyro yaw drift that gravity-only feedback
    cannot observe; in flight, attitude stays pure-gyro by design. main.c submits the
    field vector at 10Hz after each successful read.
    Note: mag axes are assumed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
    [ekf.c, main.c]
2026-06-02 docs(進度): record mag driver + GPS/mag EKF fusion (#5/#6/#7)
    更新進度.md 記錄本 session 三項已 commit 的建構單元：
    - #5-L MMC5983MA 地磁計驅動（I2C1, 0x30, 18-bit one-shot + SET/RESET 橋偏自校）— ace8625
    - #6 GPS 水平位置（E/N）融入 EKF（等距投影 + Joseph-form 標量更新，僅飛行中融合）— ddbdd3c
    - #7 地磁計航向（yaw）融入 EKF（Mahony 傾斜補償，僅發射台階段）— 0ad175d
    新增 Git 分支節點/session 變更列、階段三 checklist 三項、重要修訂紀錄
    詳述條目，並標記 #6/#7 融合需 HIL 實機驗證（磁力計軸向、Kp_mag/R
    調參、GPS 原點鎖定時機）。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
2026-06-02 fix(ekf): make EKF_GetState return an atomic cross-task snapshot
    改善項目 O：EKF_GetState() 原本無保護地拷貝 EKF_x/EKF_q/EKF_accel_bias。
    EKF_Task（osPriorityHigh）連續寫入這些狀態，而 defaultTask（Normal）於遙測 /
    FSM 頂點判斷 / SD 記錄路徑呼叫本函式讀取；High-prio 任務可在拷貝中途搶佔，
    造成「位置取自舊一輪、速度取自新一輪」的撕裂讀取。以 taskENTER_CRITICAL /
    taskEXIT_CRITICAL 封住拷貝（純記憶體搬移，數十週期），保證回傳一致快照。
    EKF_Task 內部亦呼叫本函式（同任務），FreeRTOS 臨界區可巢狀，安全。
    [ekf.c]
2026-06-02 refactor(adxl375): remove dead/buggy raw-parse lines, clarify axis convention
    改善項目 M（部分）：ADXL375_ReadData 原本先以「錯誤索引」解析一次三軸 raw
    （z_raw 誤用 rx_data[4] 而非 rx_data[5]），緊接著又用正確索引重算覆蓋，前者
    為死碼且具誤導性（若日後誤刪後段正確碼會引入真實 bug）。移除死碼，僅保留
    正確解析並補上 byte-map 註解。
    不做軸向取負（M 計畫原稿的 sign-flip）：經查 BMI088 同樣於驅動層輸出感測器
    原生軸（X/Y 反向修正集中於 EKF），故目前 Flash log 內 ADXL 與 BMI 的 raw
    皆為感測器原生座標、約定一致；若在此單獨對 ADXL 取負反而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
    [adxl375.c]
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2026-06-02 docs(進度): record O/M/F improvements + deferred A/B/C/G/K rationale
    更新進度.md 記錄本 session 三項軟體層改善（已 commit）：
    - #8-O EKF_GetState 原子快照（修跨任務撕裂讀取）— 478329a
    - #9-M(部分) ADXL375 解析死碼清理（不做 sign-flip，理由詳述）— 3266a0b
    - #10-F Flash 寫入速率 FSM 分級（飛行 50Hz；100Hz 需先做 G）— 0a03cf8
    更新分支節點表（最新 0a03cf8）、session 變更列、階段三 checklist 三項、
    重要修訂紀錄詳述條目。明確記載暫緩項與理由：A/B（HIL + 單位修正 / ISR 重構，
    已備設計文件）、C+G（SPI3 mutex + 擦除非同步化，需上板時序驗證）、K（LoRa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
2026-06-02 feat(ekf): fuse ADXL375 in EKF predict when BMI088 saturates (>20g)
    改善項目 A：EKF 預測步高G感測器切換。
    BMI088 量程 ±24g，火箭加速段可達 30-100g 而飽和；本次實作當 EKF
    樣本組裝迴圈偵測到 BMI088 加速度幅值 > 20g（196 m/s²）時，改以
    ADXL375（±200g，0.049g/LSB）對應時刻的 batch 樣本替換（i×3 索引
    近似 1ms 對齊，32筆/10ms@3200Hz / 10筆@1000Hz ≈ 3.2）。
    重要發現（修正設計文件 #3 的前置阻斷項分析）：
    - 單位已正確：main.c 在 BMI 插值後立即 ×9.80665 轉換為 m/s²，
    EKF_Predict 以 m/s² - GRAVITY 積分速度，路徑一致；設計文件 #3
    所指「g↔m/s² 單位不一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
    [main.c]
2026-06-02 feat(led): GPS fix → STAT1 LED, mag data → STAT2 LED
    每 100ms 更新感測器狀態 LED：
    - STAT1 (PE3)：GPS 有有效定位 (fix_valid=1) 常亮，無 fix 熄滅
    - STAT2 (PE4)：磁力計初始化成功 (mag_ok=1) 且讀取 OK (reads_ok>0) 常亮
    更新週期與 mag 讀取對齊（tick%100==0），避免 1kHz 頻繁寫 GPIO。
    [main.c]
2026-06-02 feat(led): all-LED 2s self-test at reset
    開機最早期（StartDefaultTask 入口）同時點亮三顆 LED（LED_SYS PE2、
    STAT1 PE3、STAT2 PE4）持續 2 秒，確認 LED 電路正常後全滅，
    之後由主迴圈接管（SYS=1Hz 心跳、STAT1=GPS fix、STAT2=Mag ok）。
    [main.c]
2026-06-02 fix(led): refresh IWDG during LED self-test to prevent watchdog reset
    osDelay(2000) 期間未餵狗，IWDG 2.05s timeout 觸發 reset，
    導致 LED 狂閃且 buzzer 永遠跑不到。
    改為 4 × osDelay(500) + HAL_IWDG_Refresh，每 500ms 餵一次狗。
    [main.c]
2026-06-02 fix(led): improve STAT1/STAT2 sensor detection conditions
    STAT1 (GPS, PE3)：
    - 舊：只有 fix_valid=1 才亮（室內永遠不亮，無法確認模組是否正常）
    - 新：sentences_ok>0 即亮（GPS 模組有送 NMEA = 硬體正常）
    有 fix 常亮；有訊號但無 fix 則 2Hz 閃爍
    STAT2 (Mag, PE4)：
    - 舊：mag_ok=1 且 reads_ok>0 才亮（需等第一次讀取成功）
    - 新：mag_ok=1 即亮（I2C init 成功 = 硬體在線）
    [main.c]
2026-06-08 CAD body v6(not finished
    [body_v1.SLDPRT, body_v1_test.SLDPRT, body_v2.3mf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]
2026-06-11 feat(telemetry): total_test 全系統整合 + LoRa 雙鏈路二進制遙測
    - telemetry.c/h：77-byte packed TelemetryPacket_t（CRC-16/CCITT-FALSE），
    低優先 LoRaTelemetry_Task 5Hz 下行
    - lora_e22.c/h：E22-400T30S 433MHz UART3 透傳，AUX 背壓忙線跳過
    - lora_e80.c/h：E80-900M2213S 920MHz SX126x SPI3 非阻塞發送（DIO1 TxDone），
    RF 參數為預設值待上板驗證
    - spi3_bus.h + g_spi3_mutex：SPI3（W25Q128 Flash + E80)遞迴/優先級繼承互斥鎖
    - sensor_axis.h / attitude_math.h：感測器→body 軸向單一真相來源 + TRIAD
    （firmware 與 host 測試共用同一份）
    - soft_i2c.c/h：MMC5983 軟體 I2C bit-bang（防硬體 I2C silicon bug 鎖死）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
    [attitude_math.h, ekf.c, gps.c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]
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2026-06-11 fix(lora): P1 LoRa 健壯化 — PD6 EXTI 風暴消除 + E22 AUX 逾時回報重試
    - LORA920_BUSY (PD6)：CubeMX 設為 IT_RISING_FALLING 但 lora_e80.c 只輪詢
    BUSY 從不用中斷 —— E80 SPI 交易期間 BUSY 高頻 toggle 狂觸 EXTI9_5 ISR
    （與 BMI/ADXL 感測器中斷搶 CPU）。於 USER CODE 區 DeInit 後覆寫為純輸入
    （PD6 為 EXTI line 6 唯一使用者；CubeMX regen 後覆寫仍保留）
    - LoRaE22_Init 改回傳 HAL_StatusTypeDef：AUX 逾時不再靜默吞掉，
    main 標記 lora433_ok=0 並列印；遙測任務（最低優先）每 10s 重試 init，
    模組恢復即自動續傳
    - 驗證：make build 乾淨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
    [lora_e22.c, main.c]
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2026-06-12 feat(gps): P1 NMEA 解析加固 — 抽純函式 + 截斷污染修復 + 65 案例 host 測試
    - 新增 gps_parse.h（header-only 純邏輯，比照 sensor_axis.h 模式）：
    組句狀態機 GpsLineAsm_t、checksum、欄位切割、經緯度換算、GGA/RMC 解析
    全數自 gps.c 抽出；GPS_Data_t 一併移入（欄位無 HAL 依賴）
    - 修復截斷污染 bug：舊版超長句溢位僅清長度重來，同句剩餘位元組被當
    新句累積、遇 CRLF 升級為待解析垃圾句；且 '$' 前雜訊（開機亂碼、
    GPS_Init 後的 UBX 二進位 ACK）也會組句。新版未見 '$' 不收、溢位置
    discard 旗標丟棄至下一個 '$'，truncated 計數可觀測
    - 順手移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
    [gps.c]
2026-06-12 fix(flash): P1 環形緩衝迴繞數學抽純 header — 修整環假池量資料損毀 bug
    - 新增 flash_ring_math.h（header-only）：池量/寫入推進/擦除推進/熱啟動
    回讀位址全部抽出，幾何常數自 w25qxx.h 移入（_Static_assert 鎖定
    sector 粒度一致），編譯期斷言封包與 sector 恰好鋪滿整環
    - 修復迴繞歧義 bug：舊版 erased_end 可停在 FLASH_RINGBUF_END+1（滾動擦除
    與 PreEraseOne 的迴繞條件甚至互不一致），當寫入指標隨後迴繞回 BASE，
    pool 算出整環 15.9MB 假池量 —— 此後整圈寫入全落未擦區，NOR 覆寫 =
    資料靜默損毀（寫入函式不回讀驗證）。長 bench 浸泡（30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
    [w25qxx.h]
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2026-06-12 fix(ekf): P2 清零 -Wall 警告 — packed 成員位址經對齊區域陣列中轉
    全量 clean 重編 0 警告（原 ekf.c 兩處 -Waddress-of-packed-member）。
    Cortex-M4 對未對齊 LDR 本可容忍且 mag_offsets 實際 4-byte 對齊，
    但消除警告噪聲避免掩蓋未來真問題。
    [ekf.c]
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2026-06-12 refactor(tools): P3 serial_link.py 收斂三份腳本的串口邏輯
    - 新增 serial_link.py：DEFAULT_BAUD/PREFERRED_PORT 單一真相、auto_port()
    統一偵測優先序（實測橋接器 → USB 關鍵字；絕不退回藍牙/wlan-debug
    等虛擬埠）、open_serial() 統一錯誤診斷（含可用串口清單）
    - test_runner.py：寫死的 port/baud 改 resolve_port()/DEFAULT_BAUD，
    兩處開埠走 open_serial
    - ekf_visualizer.py：刪除自帶的 28 行 AUTO 偵測實作，改 resolve_port
    - gui_monitor.py：DEFAULT_* 取自 serial_link，scan_ports 用統一優先序
    - GroundStation/telemetry_decoder.py 刻意保持自包含（地面站筆電可能
    只複製單檔），不納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
    [serial_link.py]
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2026-06-28 feat(gs): LoRa 通訊測試分支 — UART2 命令介面 + 雙鏈路統計
    新增 gs_lora_test 模組（IS_GROUND），透過 UART2（PA2/PA3，460800 baud）
    讓電腦即時調整 E22/E80 RF 參數並觀察通訊統計：
    - gs_lora_test.c/h：UART2 環形緩衝 + 文字命令解析
    命令：help / stats [reset] / e22 freq / e80 freq|sf|bw|cr|pwr|pre|show
    統計：pkt_ok / crc_err / 封包率 / RSSI min-max-avg / SNR min-max-avg
    - lora_e80: 新增 LoRaE80_Reconfig() — 動態改頻率/SF/BW/CR/功率/前導碼後重啟 RX
    LDRO 依符號時間自動計算（≥16ms 啟用）
    - lora_e22: 新增 LoRaE22_SetFreqMHz() — 進入設定模式寫 CH EEPROM 後回透傳
    重構 e22_write_cha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
    [ground_station.c, lora_e22.c, lora_e80.c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]
2026-06-28 fix(lora): E80 驅動改寫為 LR1121 命令集 + 完整化測試與手冊
    ★ 關鍵修正：E80-900M2213S 核心是 Semtech LR1121，非 SX126x。原驅動誤用
    SX126x 指令集，在 LR1121 上完全不會動作。依 Semtech LR1121 User Manual /
    SWDR001 重寫 lora_e80.c：
    - 16-bit opcode、頻率直接以 Hz(大端 4B)帶入(非 Frf 公式)
    - 讀回應走獨立第二次 SPI 交易(先 Stat1)；IRQ 狀態含於 GetStatus(32-bit)
    - LoRa 封包型態=0x02、單一位元組 sync word(0x022B)
    - HP PA(+22dBm)；★模組內建 RF 開關接 DIO5/DIO6，以 SetDioAsRfSwitch 設定
    (採 Semtech 參考設計，須上板對照 E80 規格書驗證，否則收發不通)
    - 公開 API(Init/StartR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
    [lora_e80.c]
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2026-06-29 feat(gs): 地面站三顆板載 LED 指示燈
    地面站韌體先前完全不驅動板上 LED，只靠 UART2/USB 報狀態。補上一眼可判讀的指示：
    - PE2 LED_SYS : 1Hz 心跳閃爍 = 韌體存活、主迴圈在跑
    - PE3 LED_State1 : GPS 定位有效恆亮 = 時間對齊錨點就緒
    - PE4 LED_State2 : 收到下行封包即短亮(120ms)，隨流量閃爍 = 接收活動
    gs_leds_update() 於主迴圈與 USB 自測迴圈每週期呼叫；s_last_pkt_tick 於
    gs_handle_packet 更新。採 active-high（SET=亮，符 GPIO init 的 RESET=滅）；
    若硬體為 active-low，對調 GS_LED_ON/OFF 即可。開機橫幅加印 LED 圖例。
    build-ground 編譯成功；ground_station.c 整檔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
    [ground_station.c]
2026-06-29 avionic bay
    [Battery_v1.3mf, Battery_v1.SLDPRT, Battery_v1.STL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]
2026-06-29 fix(lora433): E22 改為設定模式回讀偵測，不再無腦印 ready
    問題：LoRaE22_Init() 只切 GPIO(M0/M1/RST) + 設旗標就回 HAL_OK，從不與模組
    通訊，故「E22 transparent mode ready」即使沒接模組也會印。AUX(PE11) 為 PULLUP，
    未接也讀 HIGH，無法判在線。
    修正：Init 加 e22_probe() —— 進設定模式回讀 CH(0x05) 暫存器，模組在線會回
    `C1 05 ...`，未接/接線錯則 UART 無回應。據此回 HAL_OK(在線)/HAL_TIMEOUT(無回應)；
    鏈路仍標記可用(s_inited=1，透傳發送靠 AUX 背壓)，回傳值僅供誠實回報 + 主航電
    每 10s 重試。內含 2 次嘗試增強健壯性。
    - lora_e22.h：更新 Init 契約說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
    [lora_e22.c, main.c]
2026-06-29 fix(lora920): E80 在線判定強化，不再對沒回應的 LR1121 謊報 rdy
    診斷實測 [LORA] 920:rdy 但 gs=0x00 busy=1 sw(HW,Type)=0x06,0x00 —— Stat1=0x00
    (MISO 接地/晶片沒回應)、Type=0x00(非 LR1121 的 0x03)，卻因舊判定只擋「四個版本
    位元全 0/全 FF」而被一個雜散 0x06 矇混過關，誤報 920 就緒。
    強化 LoRaE80_Init 在線判定：除全 0/全 FF 外，另要求
    - GetStatus 的 Stat1 不得為 0x00/0xFF（MISO 須被晶片實際驅動）
    - GetVersion 的 Type 必須為 0x03（LR1121 簽章）
    任一不符即隔離 SPI3 並回 HAL_ERROR（→ 920:off 誠實回報）。真正在線的 LR1121
    皆會通過。與先前 433 config 回讀偵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
    [lora_e80.c]
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2026-06-29 fix(lora920): HP PA regPaSupply 改 VBAT(0x01) — 修 rdy 卻無 RF 輸出
    LR1121 datasheet SetPaConfig：HP PA(PaSel=0x01) 的 regPaSupply 必須為 0x01(VBAT)；
    原本用 0x00(內部 LDO) 餵 HP PA 規格不支援，輸出極弱/近乎無 → 晶片 SPI 正常回報
    rdy(Type=0x03) 但 SDR 收不到任何 RF。改為 Semtech +22dBm 參考組合
    {PaSel=0x01, regPaSupply=0x01, paDutyCycle=0x04, paHpSel=0x07}。
    [lora_e80.c]
2026-06-29 fix(lora920): RF 開關真值表改用 Ebyte E80 手冊值（修 rdy 卻無 RF/收不到）
    依 E80-xxxM2213S 使用手冊 v1.1 p.5：E80 內部 LR1121 DIO5/RFSW0、DIO6/RFSW1 控制
    RF 開關，且手冊注3 明示『與 SEMTECH 官方 SDK 預設不同』。原驅動誤用 Semtech 預設值：
    - TX_HP 0x02→0x01：下行用 HP PA 卻把開關設成 LP 路徑，PA 沒接到天線 → SDR 全空
    - RX 0x01→0x00：地面站接收被設成 HP-TX 路徑 → 收不到
    - TX(LP)0x03→0x02、TX_HF 0x00→0x03 一併依手冊真值表更正
    手冊真值表(DIO5,DIO6)：00=RX / 01=TX-LP / 10=TX-HP / 11=TX-2.4G。
    搭配前一筆 HP PA regPaSupply=VBAT 修正，預期 922MHz 下行可在 S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
    [lora_e80.c]
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2026-06-30 diag(reset): 開機印出重置原因（查『拔 UART 就一直重啟』）
    讀 RCC->CSR 並解碼 BOR/POR/IWDG/WWDG/SOFT/LPWR/PIN 後清旗標，開機橫幅印出。
    用途：拔 UART 重啟多為電源/欠壓(BOR/POR)而非韌體；旗標跨重置保留，
    連回 UART 後可見上一輪重置原因。
    [main.c]
2026-06-30 fix(uart/wdg): USART2 RX 上拉 + 輪詢上限，修拔 UART 浮動雜訊；buzzer 改角色節奏
    主航電拔掉 UART 轉接頭就一直重啟的軟體面強化：
    - stm32f4xx_hal_msp.c：USART2 RX(PA3) GPIO_NOPULL→GPIO_PULLUP。懸空時 RX 會浮動灌入
    雜訊位元組，原 NOPULL 是根因；上拉後拔線即 idle-high，不產生雜訊。
    - main.c Poll_Serial_Commands：無上限 while 改為最多 CMD_BUFFER_SIZE 次 + 結束清
    ORE/FE/NE/PE 旗標。第二道防線，避免雜訊狂讀霸佔 CPU / 錯誤旗標卡住。
    附：開機 buzzer 改成角色節奏（PRIMARY 兩聲漸高 / GROUND 三短聲 / BACKUP 一長聲），
    耳朵即可確認燒對角色（呼應 board_conf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
    [main.c]
2026-06-30 fix(lora920): 開機不再啟動連續載波(CW) — 修主航電一直重啟
    回歸根因：開機對 920 呼叫 LoRaE80_StartCW()（連續載波、滿功率 +22dBm、永不停）。
    原本 PA 沒作用故無感；本 session 修好 HP PA(regPaSupply=VBAT)+RF 開關後，CW 變成
    『持續滿功率發射』→ 大量持續電流壓垮供電 → 拔掉 UART(少了轉接頭供電/去耦)即欠壓重啟；
    且 CW 期間無法正常封包下行，地面站永遠收不到 920。
    改：CW 收進 E80_CW_TEST 編譯旗標（預設 0）。正常開機只 init E80、留在 standby，
    由 LoRaTelemetry_Task 每包脈衝 SetTx 發送（SDR 上看到的是週期性突波而非連續載波，
    也讓 92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
    [main.c]
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2026-06-30 feat(boot): 開機橫幅印版本+角色 ×3；Makefile 產生版本標頭 + 硬化角色還原
    開機橫幅（main.c, 每次重啟、USART2 起來後）：
    - 印 [BOOT] RocketCom FW=<FIRMWARE_VERSION> ROLE=<PRIMARY/BACKUP/GROUND> (git=.. build=..) 重複 3 次
    （剛接序列埠/雜訊環境也至少看得到一次；角色用耳朵(buzzer)+眼睛(banner)雙確認）
    - 版號 FIRMWARE_VERSION 仍在 board_config.h 手動維護；git 版次/建置時間由 build_version.h 帶入
    - build_version.h 不存在時(如直接用 CubeIDE) 以 __has_include 退回 nogit + __DATE__/__TIME__
    Makefile：
    - 新增 gen-version：建置前自動產生 Main_Code/Core/Inc/build_version.h（git describe +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
    [main.c]
2026-07-10 refactor(repo): 重整目錄結構為 firmware/hardware/ground_station/documentation/simulation_and_data
    - 韌體 Main_Code/ → firmware/；PCB 與 CAD → hardware/；地面站 → ground_station/；
    文件 → documentation/；Python 工具與資料 → simulation_and_data/
    - 3D/CAD 以遠端最新為準：補齊 avionic bay 最新 19 個 CAD（Battery_v1、GPS_v1、
    body_v6~v10、lid_v8、waterrr_M12），其中 body_v6 更新為最新版
    - 其餘非 3D 檔案採本地重組版本
    - 保留 DeployTest0613/0614/STM32 開傘測試碼於頂層
    [.step, 5.8Ghz video transmission system.step.STEP, AMASS_XT60-M_1x02_P7.2mm_Vertical.step.STEP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]
2026-07-10 refactor(ground_station): 消除重複目錄，GS 硬體/韌體歸位
    - GroundStation/GroundStation → hardware/ground_station/GroundStation（PCB）
    - GroundStation/Library.pretty → hardware/ground_station/Library.pretty（保留 ../Library.pretty 相對路徑）
    - GroundStation/GroundStation_MX → firmware/ground_station_mx（CubeMX 韌體設定）
    - telemetry_decoder.py / HARDWARE.md / 備注.md → ground_station/
    - 移除頂層與 ground_station/ 重複的 GroundStation/
    [GroundStation.kicad_pcb, GroundStation.kicad_sch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]
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2026-07-16 fix(sensor): MMC5983 連續量測模式位元修正 + P0 飛行安全累積改動
    MMC5983 磁力計 CTRL2 (0x0B) Cmm_en 誤寫在 bit4，實為 bit3（0x15 → 0x0D），
    導致連續量測模式從未真正開啟：輸出暫存器凍結，只在每 10s 軟體 SET/RESET
    校準時更新一筆（且末筆為 RESET 負極性，Output=-H+Offset）。此為近期磁力計
    「讀值不動」「地面站校正收點極慢」「航向角量測異常」等一連串現象的根因。
    Recalibrate() 前後改為暫停/恢復 CMM，避免量測期間狀態未定義。
    一併收斂近期累積的 P0 飛行安全相關改動：
    - vertical_filter.h：3 狀態 Kalman 垂直通道（Schultz 架構），與 6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
    [adxl375.c, board_config.h, ekf.c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]
2026-07-16 feat(ground_station): 磁力計校正 UI 修正 + LoRa 面板確認 + 手動指令列
    地面站 gui_monitor.py 磁力計硬鐵校正面板此前存在多項與韌體不匹配的問題：
    - CMD_MAG_CAL 命令送浮點數，但韌體 sscanf("%ld") 只吃整數（nano.specs
    不支援 %f）→ 一律送整數
    - 寫入確認字串比對不到韌體實際回印格式（多了 "(x10)" 標記與 10 倍縮放）
    → 修正比對字串並 ÷10 還原
    - 圓擬合出的硬鐵中心是 body frame，但寫回的是晶片軸 offset，兩者直接相加
    → 依 sensor_axis.h 映射關係修正軸配對
    - 寫入/重置改為等待韌體 [CAL] 回傳才提示成功，不再「送出即報成功」
    - 送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
    [telemetry_decoder.py]
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

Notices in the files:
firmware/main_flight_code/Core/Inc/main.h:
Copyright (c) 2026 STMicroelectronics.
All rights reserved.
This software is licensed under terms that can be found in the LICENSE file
